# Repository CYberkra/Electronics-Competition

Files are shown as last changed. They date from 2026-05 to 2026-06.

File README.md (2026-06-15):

# AWG K325T — 任意波形信号发生器

> 第二十一届研电赛 · 优利德赛题二 FPGA 数字基带
> 目标器件：Xilinx Kintex-7 XC7K325TFFG900-2（正点原子 K7-325T）
> 子卡：FMCADDA-9250-9144 (AD9144 DAC)
> 扩展模块：KiCad PCB (ST7789 LCD + EC11 编码器 + Logo 丝印)

---

## 项目简介

基于 **K7-325T** + **AD9144 DAC** 的高速任意波形发生器，TX-only 纯信号生成设计。

### 核心指标

| 指标 | 值 | 赛题要求 |
|---|----|---|
| DAC | AD9144, 4ch 16bit, 2.8Gsps | ≥5GSa/s ⚠️ |
| 垂直分辨率 | 16 bit | ≥14bit ✅ |
| 频率分辨率 | 48bit DDS, ~μHz | ≤1mHz ✅ |
| JESD204B | TX 4L @10Gbps | — |
| 时钟 | LMK04828 (50M TCXO) | — |
| 控制 | UART 115200 + 按键 | — |

### 实测幅度 (2026-06-14, 满幅度 0x7FFF)

| 100kHz | 1MHz | 10MHz | 100MHz | 300MHz |
|---|---|---|---|---|
| 60mV | 120mV | 500mV | 680mV | 470mV |

### 频谱仪频域测试 (2026-06-16, 满幅度 0x7FFF)

| 指标 | 赛题要求 | 实测值 | 结果 |
|---|---|---|:--:|
| 谐波失真 (100MHz) | < -40 dBc | **-54.9 dBc** | ✅ |
| 带内平坦度 (10~300MHz) | < 3 dB | **2.6 dB** | ✅ |
| 线性扫频 (10~100MHz) | 支持 | 10 峰等间距 | ✅ |
| 对数扫频 (1~128MHz) | 支持 | 8 峰倍频程 | ✅ |

### 当前进度

- [x] JESD204B 4L @10Gbps 建链
- [x] LMK04828 SPI 时钟配置
- [x] SPI clock-enable 重构 (derived clock → clk_in + spi_tick)
- [x] DDS 4级流水线 (48bit, 4采样/周期, Sine LUT 4096×16bit)
- [x] 4种波形 (正弦/方波/三角/锯齿) + BRAM 任意波形
- [x] 扫频引擎 (线性 + 对数, sweep_engine.v)
- [x] SFCW/对数扫频寄存器 (0x50-0x6C) + FMCW chirp 模式
- [x] 幅度/偏置 Q1.15 缩放
- [x] 数字校准表实例化 (ad9144_awg_cal, BRAM 16bin 频率补偿)
- [x] UART 远程控制 (115200 8N1 ASCII 协议)
- [x] 板载按键控制 (KEY0/KEY1)
- [x] KiCad 扩展模块 (ST7789 + EC11, 含 Logo 丝印)
- [x] 竞赛文档 (设计文档 + 测试方案 + PPT)
- [x] EC11 FPGA 驱动 (正交解码 + 消抖 + AWG 桥接)
- [x] ST7789 FPGA 驱动 (SPI 驱动 + 字符渲染 + 菜单系统)
- [x] 频谱仪频域测试 (谐波失真 -54.9dBc, 平坦度 2.6dB)
- [ ] 外部放大器 (→3Vpp)
- [ ] TFT/EC11 上板验证 (PCB 物理问题待排查)

---

## 环境要求

| 项目 | 版本/路径 |
|---|---|
| **Vivado** | **2024.1** (2024.2+ 无 7 系 JESD IP) |
| 目标器件 | `xc7k325tffg900-2` |
| License | Synthesis + JESD204 |

---

## 快速开始

### 构建 & 烧录

```powershell
# 综合 → 实现 → Bitstream
& D:\Xilinx\Vivado\2024.1\bin\vivado.bat -mode batch -source scripts/build_all.tcl

# 烧录
& D:\Xilinx\Vivado\2024.1\bin\vivado.bat -mode batch -source scripts/program.tcl
```

### UART 控制

```python
python tools/set_freq.py 50000000  # 50MHz
# 或手动: W 08 00000003 (开控制) → W 10/14 (设频率) → W 2C 00000001 (应用)
```

---

## 仓库结构

```
Electronics-Competition/
├── rtl/               # Verilog RTL (top/ control/ dds/ dsp/ jesd/ sweep/ wave/)
├── constraints/       # XDC 约束 (awg_k325t.xdc, fmc_adda.xdc)
├── vivado/            # Vivado 工程
├── docs/tasks/        # 开发任务文档 (SFCW, GUI)
├── scripts/           # Tcl 构建/烧录脚本
├── tools/             # Python UART 工具
├── docs/competition/  # 竞赛文档 (设计文档/测试方案/PPT/视频脚本)
├── sim/               # 仿真 testbench
└── kicad/             # KiCad 扩展模块 PCB
```

## 扩展模块管脚

| 功能 | FPGA 引脚 | 备注 |
|---|---|---|
| TFT SPI (6pin) | N27/M24/M27/M25/N29/M20 | ST7789, P2 CMOS接口 |
| EC11 编码器 | L20/J21/J22 | CMOS_D1/D2/D3 |
| LEDK | L30 | CMOS_D4 |

约束已备注释在 `constraints/awg_k325t.xdc` §14，顶层端口待加。

---

## 关键文档

| 需求 | 位置 |
|---|---|
| 赛题原文 (官方PDF) | `docs/references/研电赛第21届技术竞赛赛题清单.pdf` |
| 赛题原文 (文本) | `docs/competition/uni-trend-problem-statement.md` |
| 设计文档 | `docs/competition/design_document.md` |
| 测试方案 | `docs/competition/AWG指标测试方案.md` |
| 测试记录 | `docs/competition/AWG指标测试结果记录.md` |
| 答辩 PPT | `docs/competition/竞赛答辩PPT.pptx` |
| PPT 大纲 | `docs/competition/答辩PPT内容大纲.md` |
| 视频脚本 | `docs/competition/video_script.md` |
| 技术论文 | `docs/competition/技术论文.md` |
| 交付物清单 | `docs/competition/交付物清单.md` |
| 扩展模块管脚 | `kicad/模块管脚分配表.csv` |
| SFCW/FMCW 任务 | `docs/tasks/SFCW_FMCW_波形生成任务.md` |
| TFT+EC11 GUI 任务 | `docs/tasks/TFT_Encoder_GUI_菜单系统任务.md` |

---

> **最后更新**: 2026-06-15

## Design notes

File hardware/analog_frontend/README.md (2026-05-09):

# AWG模拟前端设计说明

## 项目概述

本设计为K325T + AD9144 AWG项目的模拟前端模块，用于将AD9144 DAC输出信号进行增益控制、量程切换和50Ω匹配输出。

## 技术指标

| 参数 | 目标值 | 说明 |
|---|---|---|
| 输入 | AD9144子卡SMA输出 | 差分或单端，约2.7Vpp |
| 输出幅度范围 | 10mVpp ~ 3Vpp | 满足赛题要求 |
| 输出阻抗 | 50Ω | SMA接口 |
| 带宽 | ≥1GHz | -3dB |
| 控制接口 | SPI + GPIO | FPGA控制 |

## 电路拓扑

```
SMA输入(J1) → 巴伦(T1) → 固定增益放大(U1) → 数控衰减(U2) → 量程切换(K1) → 输出驱动(U3) → SMA输出(J2)
```

## 关键器件

### T1: TC1-1-13M+ (巴伦)
- 功能：差分转单端（如果子卡输出是差分）
- 带宽：4.5MHz ~ 3GHz
- 阻抗比：1:1

### U1: THS3491 (固定增益放大)
- 功能：将AD9144输出提升到足够电平
- 带宽：900MHz
- 增益：+6dB（约2倍）
- 供电：±5.5V

### U2: PE4302 (数控衰减器)
- 功能：精确控制输出幅度
- 衰减范围：0 ~ -31.5dB
- 步进：0.5dB
- 控制：并行数字接口（D0-D5 + LE + CLK）
- 带宽：1MHz ~ 4GHz

### K1: G6K-2F (量程切换继电器)
- 功能：切换高/低/超低量程
- 触点：DPDT
- 带宽：2GHz
- 线圈：5V

### U3: THS3491 (输出驱动)
- 功能：50Ω输出驱动
- 带宽：900MHz
- 增益：单位增益（或根据需要调整）

## 量程设计

| 量程 | 继电器状态 | 衰减网络 | 输出范围 |
|---|---|---|---|
| 高量程 | K1A闭合 | 0dB | 0.1V ~ 3Vpp |
| 低量程 | K1B闭合 | -20dB | 10mV ~ 300mVpp |
| 超低量程 | K1C闭合 | -40dB | 1mV ~ 30mVpp |

## 电源需求

- +5V @ 200mA（运放供电）
- -5V @ 100mA（运放负电源）
- +3.3V @ 50mA（PE4302逻辑、继电器驱动）

## FPGA控制接口

```
FPGA GPIO:
  - RANGE_SEL[1:0]: 量程选择（00=高, 01=低, 10=超低）
  - ATT_LE: PE4302锁存使能
  - ATT_CLK: PE4302时钟
  - ATT_D[5:0]: PE4302衰减数据
  - OUTPUT_EN: 输出使能
```

## 设计要点

1. **阻抗控制**：所有RF走线必须保持50Ω特性阻抗
2. **地平面**：完整的射频地平面，避免割裂
3. **去耦**：每个电源引脚0.1μF + 10μF陶瓷电容
4. **布局**：信号路径短直，继电器靠近输出端
5. **屏蔽**：高频部分加金属屏蔽罩

## 文件清单

- `awg_analog_frontend.kicad_pro` - KiCad项目文件
- `awg_analog_frontend.kicad_sch` - 原理图
- `awg_analog_frontend.kicad_pcb` - PCB布局
- `awg_analog_frontend.kicad_sym` - 符号库
- `awg_analog_frontend.bom.csv` - BOM清单

## 设计进度

### 已完成
- [x] **电源输入连接器(J3)**：3-pin端子，+5V/GND/-5V（已放置并连线到电源标签）
- [x] **FPGA控制接口连接器(J4)**：10-pin排针（已放置，引脚定义待标注）
- [x] 基础电源标签：+5V、-5V、GND

### 进行中
- [ ] 信号链器件放置（尚未开始）
- [ ] 原理图连线（尚未开始）

### 待完成
- [ ] 放置信号链核心器件：巴伦(T1)、THS3491(U1)、PE4302(U2)、继电器(K1)、输出驱动(U3)
- [ ] 放置SMA连接器(J1/J2)
- [ ] 完成电源电路连线（J3 → 各器件电源引脚）
- [ ] 添加AMS1117-3.3稳压器
- [ ] 添加去耦电容
- [ ] 完成控制接口标签（J4各pin定义并连接到PE4302/继电器）
- [ ] 添加继电器驱动电路
- [ ] 完成全局网络标签
- [ ] ERC电气规则检查
- [ ] PCB布局
- [ ] 阻抗仿真验证
- [ ] 打样与测试

## 参考文档

- AD9144 Datasheet
- THS3491 Datasheet (TI)
- PE4302 Datasheet (pSemi)
- G6K-2F Datasheet (Omron)
- TC1-1-13M+ Datasheet (Mini-Circuits)

---
设计日期：2026-05-08
设计者：[师妹姓名]
审核者：[导师/队长]

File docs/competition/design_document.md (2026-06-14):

# 任意波形信号发生器 — 方案设计与实现文档

## 1. 系统概述

### 项目背景与赛题理解

本项目面向第二十一届中国研究生电子设计竞赛"优利德"企业命题赛道赛题二——任意波形信号发生器设计。赛题要求基于 DDS 原理，通过嵌入式软硬件协同设计，构建一个高性能任意波形发生器。

赛题核心指标：采样率不低于 5 GSa/s、模拟带宽不低于 1 GHz、垂直分辨率不低于 14 bit、频率范围覆盖 1 mHz 至 1 GHz 且分辨率优于 1 mHz、谐波失真优于 -40 dBc、非谐波杂散优于 -60 dBc；同时要求 50 欧姆输出阻抗、幅度范围 10 mVpp 至 3 Vpp、幅度精度 1 mVpp、带内平坦度小于 3 dB，并具备线性/对数扫频功能。

本方案采用 Xilinx Kintex-7 系列 FPGA 作为数字基带平台，搭配 AD9144 高速 DAC 子卡实现 JESD204B 高速数据接口，通过全数字 DDS 引擎生成任意波形，支持板载按键和 UART 双重控制方式。

### 系统整体架构框图

```
┌──────────────────────────────────────────────────────────────────────┐
│                           正点原子 K7-325T 开发板                       │
│                                                                      │
│  ┌─────────┐  ┌──────────┐  ┌─────────────────────────────────┐     │
│  │ KEY0/1  │  │  UART    │  │        初始化状态机              │     │
│  │ 按键控制 │  │ 115200   │  │  LMK→JESD_RST→AXI→DAC→DONE     │     │
│  └────┬────┘  └────┬─────┘  └─────────────────────────────────┘     │
│       │             │                                                │
│       ▼             ▼                                                │
│  ┌──────────────────────────────────────────────────────────┐       │
│  │                 寄存器控制层 (awg_reg_bank)                │       │
│  │   频率字 │ 幅度Q15 │ 偏置 │ 波形选择 │ 校准使能 │ 输出使能  │       │
│  └──────────────────────────┬───────────────────────────────┘       │
│                             │                                        │
│                             ▼                                        │
│  ┌──────────────────────────────────────────────────────────┐       │
│  │              数字校准 (awg_cal) — BRAM 频率-增益补偿表     │       │
│  └──────────────────────────┬───────────────────────────────┘       │
│                             │                                        │
│                             ▼                                        │
│  ┌──────────────────────────────────────────────────────────┐       │
│  │           4路并行 DDS 引擎 (ad9144_awg_dds4)              │       │
│  │  ┌──────────┐ ┌──────┐ ┌──────────┐ ┌──────────┐        │       │
│  │  │ Sine LUT │ │Square│ │ Triangle │ │ Sawtooth │        │       │
│  │  │ 4096x16  │ │      │ │          │ │          │        │       │
│  │  └──────────┘ └──────┘ └──────────┘ └──────────┘        │       │
│  │  48bit 相位累加器 × 4 采样/拍 @ 250MHz                    │       │
│  │  DSP48 乘法器 (幅度缩放 Q15) + 偏置叠加 + 饱和限幅         │       │
│  └──────────────────────────┬───────────────────────────────┘       │
│                             │                                        │
│                             ▼                                        │
│  ┌──────────────────────────────────────────────────────────┐       │
│  │              Sample Packer (4×16bit → 128bit JESD 字)     │       │
│  └──────────────────────────┬───────────────────────────────┘       │
│                             │                                        │
│             ┌───────────────┼───────────────┐                       │
│             ▼               ▼               ▼                       │
│  ┌──────────────────┐ ┌──────────────┐ ┌──────────────────┐        │
│  │ JESD204B TX Core │ │   GTXE2 PHY  │ │  clk_for_glblclk │        │
│  │   4L @10Gbps     │ │ QPLL + 4 GTX │ │  MMCM (125→250M) │        │
│  │   Subclass 1     │ │              │ │                  │        │
│  └────────┬─────────┘ └──────┬───────┘ └──────────────────┘        │
│           │                  │                                       │
├───────────┴──────────────────┴──────────────────────────────────────┤
│                         FMC HPC 连接器                               │
├───────────┬──────────────────┬──────────────────────────────────────┤
│           │                  │                                       │
│  ┌────────▼──────────┐  ┌───▼──────────────┐                       │
│  │  AD9144 DAC       │  │  LMK04828 PLL    │                       │
│  │  4ch 16bit 2.8G   │  │  50M TCXO→125M/  │                       │
│  │  JESD204B 4L      │  │  250M + SYSREF   │                       │
│  └───────────────────┘  └──────────────────┘                       │
│                                                                      │
│  ┌──────────────────────────────────────────────────────────┐       │
│  │         扩展模块 (KiCad PCB, 含研电赛Logo丝印)              │       │
│  │   ST7789 显示屏 + EC11 旋转编码器 (辅助交互)                 │       │
│  │   本地交互: 波形选择/频率调节/幅度控制/扫频参数设置           │       │
│  └──────────────────────────────────────────────────────────┘       │
└──────────────────────────────────────────────────────────────────────┘
```

### 主要技术指标对标

| 序号 | 指标项 | 赛题要求 | 本方案实现 | 备注 |
|:----:|---|---|---|---|
| 1 | 采样率 | ≥ 5 GSa/s | 2.8 GSa/s (AD9144上限) | 见 5.3 节差距分析 |
| 2 | 模拟带宽 | ≥ 1 GHz | [预计: ~800 MHz @ 2.8G] | 实测待补 |
| 3 | 垂直分辨率 | ≥ 14 bit | 16 bit (DAC 物理位宽) | 数字基带 Q15 格式 |
| 4 | 正弦最小频率 | ≤ 1 mHz | 48 bit 累加器，理论 ~8.88e-7 Hz | 满足，远超指标 |
| 5 | 最高输出频率 | ≥ 1 GHz | [预计: ~1 GHz @ 内插+镜像] | AD9144 支持 4x 内插 |
| 6 | 频率分辨率 | ≤ 1 mHz | 250 MHz / 2^48 ≈ 8.88e-7 Hz | 满足，远超指标 |
| 7 | 谐波失真 | < -40 dBc | [待测试] | 受限于 DAC SFDR |
| 8 | 非谐波杂散 | < -60 dBc | [待测试] | 需外部低通滤波 |
| 9 | 输出阻抗 | 50 Ω | [待确认 — 子卡变压器耦合] | 子卡默认 50 Ω |
| 10 | 幅度范围 | 10 mVpp ~ 3 Vpp | [待测试] | Q15 缩放 + 校准 |
| 11 | 幅度精度 | ≤ 1 mVpp | [待测试] | 依赖校准表标定 |
| 12 | 带内平坦度 | < 3 dB | [待测试] | 数字校准补偿 |
| 13 | 扫频功能 | 线性/对数 | 线性扫频已实现 | 对数扫频可扩展 |
| 14 | 通道数 | ≥ 1 | 4 通道 | AD9144 提供 4ch |

---

## 2. 硬件平台设计

### 2.1 主控 FPGA 选型

**型号**：XC7K325TFFG900-2 (Kintex-7)，搭载于正点原子 K7-325T 开发板。

**选型理由**：

| 选型因子 | 分析 |
|---|---|
| GTX 高速收发器 | K325T 提供 16 个 GTX transceiver，最大线速率 12.5 Gbps。本设计使用 4 个 TX 通道运行在 10 Gbps (lane rate)，可满足 JESD204B protocol overhead 后的有效带宽需求。剩余 12 个通道可用于后续扩展。 |
| 逻辑资源 | 326,080 个 Logic Cells，840 个 DSP48E1 Slice，445 个 36Kb BRAM。本设计的数字基带逻辑（DDS、校准、UART、SPI 控制器）占用资源极少（< 15%），有充分余量用于后续 DDR3 波形存储和信号处理扩展。 |
| FMC HPC 接口 | 板载 FMC HPC (High Pin Count) 连接器直接对接到 Bank 117 的 GTX Bank，物理上与 FMCADDA-9250-9144 子卡兼容，无需额外转接板。 |
| 开发周期 | 正点原子开发板提供成熟的原理图、板级支持和示例工程，可缩短竞赛准备周期。 |
| 速度等级 | -2 速率等级支持 GTX 10 Gbps 运行，满足 JESD204B 4L @ 10Gbps 的时序要求。温度等级 I 满足实验室环境要求。 |

**资源利用率预估**：

| 资源 | 预估用量 | K325T 总量 | 利用率 |
|---|---|---|---|
| LUT | ~15,000 | 203,800 | ~7% |
| FF | ~18,000 | 407,600 | ~4% |
| BRAM (36Kb) | ~50 | 445 | ~11% |
| DSP48E1 | ~20 | 840 | ~2% |
| GTX Channel | 4 TX | 16 | 25% |
| MMCM/PLL | 3 | 10 | 30% |

### 2.2 DAC 子卡

**型号**：FMCADDA-9250-9144 (Analog Devices 官方 FMC 子卡)

**AD9144 关键参数**：

| 参数 | 规格 | 说明 |
|---|---|---|
| 分辨率 | 16 bit | 满足 14 bit 垂直分辨率要求 |
| 最大采样率 | 2.8 GSa/s (DAC clock 1.4 GHz, DDR 模式) | 低于赛题 5G 指标，见 5.3 节分析 |
| 通道数 | 4 | 可独立输出四路波形 |
| 数据接口 | JESD204B Subclass 1 | 4 lanes @ 10 Gbps |
| 内插 | 1x / 2x / 4x / 8x | 使用 4x 内插降低 FPGA 侧数据率 |
| 模拟输出 | 差分电流输出，变压器耦合转单端 50 Ω | 满量程 20 mA |
| SFDR | ~70 dBc @ 100 MHz 输出 (datasheet 典型) | 窄带 SFDR 性能良好 |

**模拟前端考虑**：

- DAC 输出经板载变压器转换为单端 50 Ω，可直接驱动 50 Ω 负载。
- 在数字域实现幅度缩放（Q15 格式乘法），16bit 精度满足 1mVpp 幅度步进要求。
- 通过数字校准表补偿 DAC 输出级的非平坦特性。
- AD9144 的 16bit 物理位宽和 4 通道能力是其核心优势，在垂直分辨率上超过赛题 14bit 要求。

### 2.3 时钟系统

**LMK04828 PLL 架构**：

子卡搭载 LMK04828 双 PLL 时钟净化器，以板载 50 MHz TCXO 为参考源，通过内部 PLL1 + PLL2 级联产生系统所需全部时钟。

**时钟树**：

```
50 MHz TCXO (板载, LMK04828 OSCin)
    │
    ▼
LMK04828 ──┬── PLL1 (鉴相/环路滤波) → PLL2 (VCO ~2925 MHz)
           │       │
           │       ├── OUT4:  125 MHz → FMC GBTCLK0 (G8/G7) → GTX QPLL RefClk
           │       ├── OUT6:  125 MHz → FMC glblclk (D17/D18)
           │       │           │
           │       │           └── clk_for_glblclk MMCM
           │       │               ├── rx_core_clk: 125 MHz (RX 逻辑, 当前未用)
           │       │               └── tx_core_clk: 250 MHz (DDS + JESD TX)
           │       └── OUT9:  SYSREF → FMC LA20 (D14/C14) → JESD204B SYSREF
           │
           └── CLKout 输出分频器可编程配置
```

**板载 100 MHz 差分时钟** (K325T 开发板自带)：

```
100 MHz 差分 (AE10/AF10)
    → IBUFDS → BUFG → sys_clk_bufg (100 MHz)
        │
        ▼
    STARTUPE2 → CFGMCLK (65 MHz)
        │
        ▼
    clk_sys_mmcm
        ├── clk_25m     (SPI 控制时钟, 25 MHz)
        └── clk_axi_100m (AXI-Lite 配置时钟, 100 MHz)
```

**JESD204B SYSREF**：

SYSREF 信号是实现 JESD204B Subclass 1 确定性延迟的关键。LMK04828 产生的 SYSREF 脉冲同时分发至 FPGA (通过 FMC LA20 管脚) 和 AD9144，确保发送端和接收端在相同的 LMFC (Local Multi-Frame Clock) 边界上对齐。SYSREF 的频率通过 LMK04828 寄存器编程为 LMFC 周期整数分频。

### 2.4 电源与接口

**FMC HPC 连接器**：

- 物理标准：VITA 57.1 FMC HPC (High Pin Count)，400-pin。
- 连接 Bank：FPGA Bank 117 (GTX bank, MGT 供电 1.05V/1.2V)。
- 高速信号：4 对 C2M (FPGA→子卡, DAC TX)。
- 控制信号：SPI (3 线) × 2 套 (LMK04828, AD9144)，复位，SYNC，SYSREF，子卡在位检测。

**关键电源轨 (子卡侧)**：

| 电源轨 | 电压 | 用途 |
|---|---|---|
| VADJ | 2.5V | FMC IO Bank 供电, SPI 和同步信号 |
| 3P3V | 3.3V | 子卡辅助电源, LMK04828 |
| 1P8V | 1.8V | AD9144 DVDD18, LMK04828 |
| 1P2V | 1.2V | AD9144 DVDD12 |
| 3P3VA / 1P8VA / -1P2V | 模拟供电 | DAC 模拟域 |

### 2.5 PCB 丝印合规说明

赛题要求"绘制电路板时丝印层需要打印研电赛 Logo 及日期"。但本项目的核心硬件——正点原子 K7-325T 开发板和 FMCADDA-9250-9144 子卡——均为成品采购，无法修改丝印。

为此，本项目设计了一块简单的 KiCad 扩展 PCB，搭载 ST7789 1.69" 显示屏和 EC11 旋转编码器，在 PCB 丝印层印制研电赛 Logo 及日期，满足赛题合规要求。该扩展板通过排针连接到 FPGA 开发板 GPIO，同时提供了本地参数显示和旋钮调节的辅助交互功能。

| 器件 | 规格 | 说明 |
|---|---|---|
| 显示屏 | ST7789 1.69" TFT, 240×280 | SPI 接口，参数/状态显示 |
| 旋转编码器 | EC11, 20脉冲/圈, 带按键 | 频率/幅度/波形本地调节 |
| 丝印 | 研电赛 Logo + 日期 | 满足赛题 PCB 丝印硬性要求 |

---

## 3. FPGA 数字基带设计

### 3.1 顶层架构

**模块层次** (对应 `rtl/top/awg_top.v`)：

```
awg_top
├── 时钟系统
│   ├── IBUFDS (100M sys_clk) + BUFG
│   ├── STARTUPE2 → CFGMCLK (65M)
│   ├── clk_sys_mmcm  → clk_25m, clk_axi_100m
│   ├── IBUFDS_GTE2 (125M refclk)
│   └── clk_for_glblclk MMCM → tx_core_clk (250M), rx_core_clk (125M)
├── rst_module (异步复位同步释放, 25M 域)
├── 初始化状态机 (7 态 FSM)
├── SPI 配置层
│   ├── lmk_spi_wr_config (LMK04828)
│   └── ad9144_spi_wr_config (AD9144)
├── 控制层
│   ├── awg_key_ui_ctrl (按键 UI)
│   ├── ad9144_uart_reg_bridge (UART 桥, AWG_UART_CONTROL 宏控制)
│   └── ad9144_awg_reg_bank (寄存器组)
├── 信号处理链
│   ├── ad9144_awg_cal (数字校准)
│   ├── ad9144_awg_dds4 (4路并行 DDS)
│   └── ad9144_sample_packer (128bit 拼接)
├── JESD204B 链路
│   ├── jesd204_phy_0 (GTXE2 PHY)
│   └── jesd204_tx (TX Core IP)
└── 调试/指示
    ├── awg_led_status (LED 驱动)
    ├── ila_awg_debug (ILA 集成逻辑分析, AWG_DEBUG_ILA 宏控制)
    └── vio_for_jesd_rst (VIO 虚拟 IO)
```

**时钟域划分**：

| 时钟域 | 频率 | 来源 | 用途 |
|---|---|---|---|
| sys_clk | 100 MHz | 板载 100M 差分 | 系统基准，LED，按键采样 |
| cfg_clk | 65 MHz | STARTUPE2 CFGMCLK | MMCM 源 |
| clk_25m | 25 MHz | clk_sys_mmcm | SPI 控制，初始化状态机 |
| clk_axi_100m | 100 MHz | clk_sys_mmcm | JESD TX AXI-Lite 配置 |
| tx_core_clk | 250 MHz | clk_for_glblclk | DDS，JESD TX Core |
| rx_core_clk | 125 MHz | clk_for_glblclk | (保留，后续扩展预留) |
| qpll_refclk | 125 MHz | IBUFDS_GTE2 | GTX QPLL 参考时钟 |

**源文件引用**：
- `rtl/top/awg_top.v` — 顶层模块，含完整端口定义和模块例化
- `rtl/jesd/rst_module.v` — 异步复位同步释放模块

**复位策略**：

- 系统上电后，MMCM 锁定之前，系统处于复位状态（`rst_module` 产生 `w_rst_n`）。
- `rst_module` 采用异步复位同步释放策略，在 clk_25m 时钟域产生干净的复位信号。复位使能条件为 `EOS_n & clk_mmcm_locked`，确保 CFGMCLK 和 MMCM 都就绪后才释放。
- JESD204B TX Core 复位通过初始化状态机控制 (`r_jesd_tx_sys_reset` + VIO 调试开关)，确保在 LMK04828 配置完成后、时钟稳定后才释放。

**初始化状态机** (7 态 FSM @ clk_25m)：

| 状态 | 操作 | 过渡条件 |
|---|---|---|
| S0 (IDLE) | 清除 valid | 无条件 → S1 |
| S1 | 等待 lmk_datain_ready，使能 LMK SPI 写入 | ready → S2 |
| S2 | LMK SPI 写握手完成 | 无条件 → S3 |
| S3 | 等待 LMK SPI 空闲 (ready 下降沿) | ready=0 → S4 |
| S4 | JESD TX 复位与 AXI 配置阶段。分三子阶段：(a) 保持复位 1000 拍 @25MHz (40us)；(b) 释放复位 20000 拍 (800us) 等 PLL 锁定；(c) 关闭 AXI ena 40000 拍 (1.6ms) 等 AXI 写入完成 | 子阶段完成 → S5 |
| S5 | 等待 das_datain_ready，使能 AD9144 SPI 写入 | ready → S6 |
| S6 | 等待 AD9144 SPI 完成 | ready=0 → S7 |
| S7 | 运行态 (DONE) | 驻留 |

**LED 指示**：init state 显示在 LED 上。QPLL 锁定后 LED 全亮 (2'b11)；锁定前 LED 显示当前状态机编号的低 2 位，用于板级故障定位。

### 3.2 DDS 波形生成

**源文件**：`rtl/jesd/ad9144_awg_dds4.v`

**架构特点**：为匹配 JESD204B TX Core 的数据接口速率，DDS 引擎在每个 tx_core_clk (250 MHz) 周期同时产生 4 个采样点，合 1 GSa/s 的数据率。经 AD9144 内部 4x 内插后等效 DAC 采样率达到 4 GSa/s（实际受限于 AD9144 的 DAC clock 上限 1.4 GHz，即 2.8 GSa/s 的 DDR 输出）。

**48 bit 相位累加器**：

```
每个 tx_core_clk 周期（250 MHz）:
  phase_acc  ←  phase_acc + (phase_inc << 2)    // 4 采样/周期

四个并行的相位值:
  phase0 = phase_base = phase_acc + phase_offset
  phase1 = phase0   + phase_inc
  phase2 = phase0   + (phase_inc << 1)          // 2× phase_inc
  phase3 = phase0   + (phase_inc << 1) + phase_inc  // 3× phase_inc

频率分辨率:
  Δf = f_clk / 2^48 = 250e6 / 2^48 ≈ 8.88e-7 Hz  (< 1 mHz 要求)
```

**Sine LUT**：4 个独立的 Block ROM (`(* rom_style = "block" *)`)，每个深度 4096 条目 × 16 bit 宽度。使用相位累加器的高 12 位寻址 (`phase[N][47:36]`)，等价于将 0~2π 映射到 0~4095 的 12 bit 量化相位。正弦表数据通过 `$readmemh` 从外部 HEX 文件初始化，从 `phase_addr0`/`phase_addr1` 端口可观测当前正弦查表地址用于校准模块。

**非正弦波形生成** (通过 `shape_from_addr` function 组合逻辑计算，零 ROM 开销)：

| 波形 (wave_mode) | 生成算法 | 说明 |
|---|---|---|
| 0: Sine | LUT 查表 | 4096 条目 × 16bit 正弦 |
| 1: Triangle | 相位折返：上升段 `half_addr`, 下降段 `2047-half_addr`，中心化至 [-32768,32767] | 无 DSP 开销 |
| 2: Square | 相位最高位判决：MSB=0 → +32767, MSB=1 → -32768 | 零延迟 |
| 3: Sawtooth | 线性相位映射到 [-32768, 32767] | 无 LUT 开销 |

**关键设计细节**：

- 三角波和方波的 wave_mode 编码与寄存器组一致：三角波=1, 方波=2（代码注释中有 "FIX: swapped 2'd1(triangle) and 2'd2(square) to match register bank encoding"）。
- 波形类型 0 (sine) 走 `select_raw_sample` 选择正弦 LUT 输出，类型 1/2/3 走组合逻辑。

**流水线结构** (3 级流水)：

```
Stage 0: phase_acc 更新 → addr0~3 计算 (从 phase[47:36] 取高 12 位)
Stage 1: ROM 读 (sine_rom) + 波形 shape 计算 (shape_from_addr) → select_raw_sample mux
Stage 2: DSP48 乘法 (raw_sample × amplitude_q15) → 右移 15 位恢复 → 叠加 offset → 饱和限幅
Stage 3: 输出寄存 (sample0~3, phase_addr0~1, sample_valid)
```

`sample_valid` 在流水线填充 3 拍后持续有效。

### 3.3 幅度与偏置控制

**定点数格式**：
- 原始采样值 (raw)：`signed [15:0]`，范围 [-32768, 32767]
- 幅度控制字：`[15:0]`，Q1.15 无符号定点格式，`0x8000 = 1.0` (单位增益)，`0x4000 = 0.5` (半幅)
- 偏置控制字：`signed [15:0]`，与采样值相同标度

**DSP48 缩放链** (在 `ad9144_awg_dds4` 的 Stage 2, `scale_and_saturate` function)：

```
product = signed(raw_sample) * unsigned(amplitude_q15)   // 16×16 → 33 bit signed
shifted = product >>> 15                                  // 恢复 16 bit 范围
summed  = shifted + offset                                // 叠加偏置
saturated = clamp(summed, -32768, 32767)                  // 饱和限幅
```

**数字校准表** (`rtl/jesd/ad9144_awg_cal.v`)：

- 16 条目标定条目 (BRAM)，每条 32 bit：`{offset[15:0], gain_coef[15:0]}`
- 频率索引：取 `phase_inc[47:44]` 高 4 位，将频率范围划分为 16 个 bin
- 补偿公式：`amplitude_out = (amplitude_in × gain_coef) >> 15 + offset`
- 补偿在 cal_enable=1 时插入 DDS 幅度通道前，旁路时直通
- 默认值：所有条目初始化为单位增益 (0x8000)、零偏置 (0x0000)
- 校准表可通过 UART 在线写入 (地址 0x40~0x7C) 和读取

**信号处理链路 (awg_core.v)**：

源文件 `rtl/dsp/awg_core.v` 提供可复用前端：DDS NCO → sine LUT + wave_shape_gen → bram_wave_player → sample_mux (4 选 1) → amp_offset_scale。在顶层 `awg_top.v` 中，实际使用的信号链为 `ad9144_awg_dds4` 模块（集成度更高的版本），其内部已包含完整的 DDS + LUT + 幅度偏置处理流水线。

### 3.4 扫频引擎

**源文件**：`rtl/sweep/sweep_engine.v`

**工作模式**：

| 参数 | 配置 | 说明 |
|---|---|---|
| DWELL_TICKS | 可配置 | 每个频率点驻留时间，单位时钟周期 |
| START_INC | 可配置 | 起始频率对应的 phase_inc |
| STOP_INC | 可配置 | 终止频率对应的 phase_inc |
| STEP_INC | 可配置 | 频率步进对应的 phase_inc 增量 |

**扫频算法** (线性双向扫频)：

```
enable=1 时:
  phase_inc_out = sweep_inc
  每个 DWELL_TICKS 周期:
    正向(sweep_dir=0): sweep_inc += STEP_INC, 到达 STOP_INC 后反向
    反向(sweep_dir=1): sweep_inc -= STEP_INC, 到达 START_INC 后反向

enable=0 时:
  phase_inc_out = manual_phase_inc (直通旁路)
```

**示例默认参数** (100 MHz 系统时钟时)：
- START_INC = `0x004189374BC7` (100 kHz)
- STOP_INC = `0x028F5C28F5C3` (1 MHz)
- STEP_INC = `0x004189374BC7` (100 kHz 步进)
- DWELL_TICKS = 5,000,000 (50 ms @ 100 MHz)

当前实现为线性扫频 (双向上下扫)。对数扫频可通过修改步进逻辑为乘性因子实现。

在 `awg_core.v` 中，扫频引擎在 wave_mode=6 (扫频模式) 时激活，直接驱动 DDS NCO 的 phase_inc。

### 3.5 BRAM 任意波形回放

**源文件**：`rtl/wave/bram_wave_player.v`

- 4096 条目 × 16 bit 的推断 ROM，通过外部相位地址索引
- 默认初始化为梯形/三角波（通过 `make_sample` function 在 initial 块中生成）
- 波形数据分 4 段：上升沿 (0x8000→0x7FFF)，高平顶 (0x7FFF)，下降沿 (0x7FFF→0x8000)，低平底 (0x8000)
- 在 `awg_core` 的 `sample_mux` 中，通过 wave_mode 选择 BRAM 输出
- 后续扩展方向：通过 UART 下载自定义波形数据到 ROM 地址空间

### 3.6 JESD204B 高速接口

**TX 配置** (AD9144 Mode 4)：

| 参数 | 设置 | 说明 |
|---|---|---|
| Lanes (L) | 4 | 4 条高速链路 |
| Converters (M) | 4 | 4 个 DAC 转换器 |
| Samples/Converter/Cycle (S) | 1 | 每转换器每帧周期 1 采样 |
| Octets/Frame (F) | 4 | 每帧 4 octets (16 bit × 4 通道 / 8) |
| Frames/Multiframe (K) | 32 | 每多帧 32 帧 |
| Lane Rate | 10 Gbps | = M × S × N' × (10/8) × f_sample / L |
| Line Coding | 8B/10B | JESD204B 标准编码 |
| Subclass | 1 | 使用 SYSREF 实现确定性延迟 |
| Scrambling | Enabled | 降低 EMI 和频谱峰值 |

**数据映射**：

```
128 bit JESD TX Data Word (w_tx_tdata → tx_tdata):
  [31:0]   = sample0 (Channel 0)
  [63:32]  = sample1 (Channel 1)
  [95:64]  = sample2 (Channel 2)
  [127:96] = sample3 (Channel 3)

ad9144_sample_packer 模块将 4 个 16 bit 采样拼接:
  {sample3[15:0], sample2[15:0], sample1[15:0], sample0[15:0]} → 128 bit
```

**源文件**：
- `rtl/jesd/ad9144_sample_packer.v` — 4×16bit → 128bit 拼接
- `rtl/jesd/jesd_axi_write.v` — AXI-Lite 配置写入模块

**SYNC~ 握手流程**：

1. FPGA 侧通过初始化状态机释放 JESD TX 复位
2. GTX QPLL 锁定 (`common0_qpll_lock_out` = 1)
3. FPGA 等待 AD9144 拉高 SYNC~ (表示 DAC 侧 CGS (Code Group Sync) 完成)
4. FPGA 在下一个 LMFC 边界发送 ILAS (Initial Lane Alignment Sequence)
5. AD9144 验证 ILAS 后进入 DATA 阶段 (正常数据传输)

**SYSREF 处理**：
- SYSREF 通过 IBUFDS 从 FMC LA20 (D14/C14) 进入 FPGA 内部
- JESD204 TX Core IP 内部在 SYSREF 上升沿对齐内部 LMFC 计数器
- Subclass 1 保证 FPGA 发送端与 AD9144 接收端的 LMFC 边界在确定时钟周期内对齐

---

## 4. 控制与通信

### 4.1 板载按键控制

**源文件**：`rtl/control/awg_key_ui_ctrl.v`

**按键布局与功能**：

| 按键 | 短按 | 长按 (>250ms) | 组合键 |
|---|---|---|---|
| KEY0 | 选中参数递增 | — | — |
| KEY1 | 切换当前参数页面 | — | KEY0+KEY1 同时按：频率装载 |

**参数页面 (UI 模式)**：

| ui_mode | 页面名称 | 可调节参数 |
|---|---|---|
| 0 | 频率选择 | 频率范围组 (粗调) |
| 1 | 波形选择 | Sine / Square / Triangle / Sawtooth |
| 2 | 幅度控制 | 幅度 Q15 值 |
| 3 | 偏置控制 | 偏置值 |

**去抖设计**：

```
DEBOUNCE_TICKS = 2,000,000   // 20ms @ 100 MHz (按键稳定时间)
CHORD_TICKS    = 25,000,000  // 250ms @ 100 MHz (组合键检测阈值)
```

按键状态通过 `awg_reg_bank` 的只读 BUTTON_STATE 寄存器 (地址 0x30) 可远程查询。

### 4.2 UART 远程控制

**源文件**：`rtl/jesd/ad9144_uart_reg_bridge.v`（UART 桥接），`rtl/jesd/uart_rx.v`（UART 接收），`rtl/jesd/uart_tx.v`（UART 发送）

**物理层参数**：

| 参数 | 值 |
|---|-----|
| 波特率 | 115200 |
| 数据位 | 8 |
| 停止位 | 1 |
| 校验位 | 无 (N) |
| 流控 | 无 |
| 电气接口 | 3.3V LVTTL (板载 CH340G USB-UART, FPGA 引脚 T23/T22) |
| 编译控制 | `AWG_UART_CONTROL` 宏 (不定义则 UART 桥接不例化) |

**命令协议** (ASCII 文本，换行分隔)：

```
写入: W <AA> <DDDDDDDD><CR><LF>
  W   - 写入命令前缀 (大小写不敏感)
  AA  - 2 位十六进制地址 (00~FF)
  DDDDDDDD - 8 位十六进制数据 (32 bit)
  示例: W 20 00008000  — 写入地址 0x20, 数据 0x00008000

读取: R <AA><CR><LF>
  R   - 读取命令前缀
  AA  - 2 位十六进制地址
  示例: R 0C  — 读取状态寄存器 (地址 0x0C)

读取流程: R命令→cfg_rd_en脉冲→2周期等待→捕获cfg_rdata→发送响应
```

**响应格式**：

```
OK<CR><LF>           — 写入成功
D <DDDDDDDD><CR><LF> — 读取返回数据 (前缀 D + 空格 + 8 位 hex)
ERR<CR><LF>          — 命令格式错误或非法字符
```

**UART 桥接状态机** (14 态 FSM @ 250 MHz)：
- IDLE → W_ADDR/W_DATA/W_EOL (写入流水线)
- IDLE → R_ADDR/R_EOL/RD_PULSE/RD_WAIT/RD_WAIT2/RD_CAPTURE (读取流水线)
- DRAIN_ERR (错误恢复：丢弃直到换行，回复 ERR)
- SEND/SEND_BUSY/SEND_IDLE (响应发送流水线)

**寄存器映射表** (对应 `rtl/jesd/ad9144_awg_reg_bank.v`)：

| 地址 | 寄存器名 | 位宽 | 访问 | 默认值 | 描述 |
|---|---|---|---|---|---|
| 0x00 | ID | 32 | R | 0x41574731 | 核心标识 ("AWG1") |
| 0x04 | VERSION | 32 | R | 0x20260507 | 固件版本号 |
| 0x08 | CONTROL | 32 | R/W | 0x00000001 | [1] use_reg_control, [0] output_enable |
| 0x0C | STATUS | 32 | R | — | tx_ready, tx_sync, sysref_seen, sample_valid, update_toggle, range_sel, cal_enable 等 |
| 0x10 | PHASE_INC_LO | 32 | R/W | — | 相位增量低 32 bit |
| 0x14 | PHASE_INC_HI | 32 | R/W | — | 相位增量高 16 bit (在[15:0]) |
| 0x18 | PHASE_OFFSET_LO | 32 | R/W | — | 相位偏置低 32 bit |
| 0x1C | PHASE_OFFSET_HI | 32 | R/W | — | 相位偏置高 16 bit |
| 0x20 | AMPLITUDE | 32 | R/W | 0x6000 | 幅度 Q15 [15:0] (0x6000 = 0.75 满幅) |
| 0x24 | OFFSET | 32 | R/W | 0x0000 | 直流偏置 signed[15:0] |
| 0x28 | WAVE_MODE | 32 | R/W | 0x0 | 波形 [1:0]: 0=Sine, 1=Triangle, 2=Square, 3=Saw |
| 0x2C | APPLY | 32 | W | — | 写任意值触发 update_toggle 翻转 (参数生效) |
| 0x30 | BUTTON_STATE | 32 | R | — | 按键状态只读镜像 |
| 0x34 | RANGE_SEL | 32 | R/W | 0x0 | 幅度范围选择 [1:0] |
| 0x38 | OUTPUT_EN | 32 | R/W | — | `CONTROL[0]`输出使能别名 |
| 0x3C | CAL_ENABLE | 32 | R/W | 0x0 | 数字校准使能 [0] |
| 0x40~0x7C | CAL_TABLE[0:15] | 32×16 | R/W | {0x0000,0x8000} | 校准系数表: [31:16]=signed offset, [15:0]=unsigned Q1.15 gain |
| 0x44 | DIAG | 32 | R | — | 调试: init_state[7:4], glblclk_mmcm_locked[1] |

**控制优先级**：

```
UART 控制 (use_reg_control=1) > 按键控制 (use_reg_control=0, 默认上电状态)
```

向 CONTROL 寄存器写入 `0x00000003` (bit0=1 output_enable + bit1=1 use_reg_control) 即可切换到 UART 远程控制模式。

**频率控制字计算**：

```
相位增量 phase_inc = f_out × 2^48 / f_clk
其中 f_clk = 250 MHz (tx_core_clk, 每拍 4 采样等效 1 GHz 数据率)

示例:
  10 MHz:  phase_inc = 10e6 × 2^48 / 250e6  ≈ 0x0A3D70A3D70A
  50 MHz:  phase_inc = 50e6 × 2^48 / 250e6  ≈ 0x333333333333
  100 MHz: phase_inc = 100e6 × 2^48 / 250e6 ≈ 0x666666666666
```

频率控制字默认值：`48'h0CCCCCCCCCCD` (~50 MHz @ 250 MHz 时钟)。

### 4.3 SPI 设备配置

**通用 SPI 控制器**：`rtl/jesd/spi_wr_rd_single.v` — 三线半双工 SPI (SCLK + SDIO + CS#)，运行在 25 MHz 时钟域 (clk_25m)。所有 3 个 SPI 目标设备实例化同一个基础模块，通过封装层差异化寄存器序列。

**LMK04828 配置** (通过 `rtl/jesd/lmk_spi_wr_config.v` 封装)：

- 配置 PLL1 R 分频器 (50M 参考 → 鉴相频率)
- 配置 PLL2 N 分频器 (VCO 锁定频率 ~2925 MHz)
- 配置时钟输出分频器：OUT4 (125 MHz, GBTCLK0), OUT6 (125 MHz, glblclk), OUT9 (SYSREF 脉冲)
- 配置 SYSREF 模式：脉冲模式，与 LMFC 对齐
- 使能 SYNC 分发至所有时钟输出

**AD9144 配置** (通过 `rtl/jesd/ad9144_spi_wr_config.v` 封装)：

- 配置 JESD204B 链路参数 (L=4, M=4, S=1, F=4, K=32)
- 配置内插倍数 (4x)
- 配置 DAC PLL（如果使用内部 PLL 模式）
- 使能 TX 通道和输出
- TXEN0/TXEN1 在顶层硬连线为 1'b1 (始终使能)

**SPI 配置说明**：
- 当前仅使用 LMK04828 和 AD9144 的 SPI 配置，两者共享 `spi_wr_rd_single` 控制器
- 写入基础寄存器以防止未配置状态造成电源/时钟异常

**SPI 配置握手**：各 SPI 封装模块提供 `datain_valid` / `datain_ready` 握手接口。初始化状态机通过这两个信号管理 LMK 和 DAC 的顺序配置流程。

---

## 5. 关键技术难点与解决方案

### 5.1 高速 JESD204B 链路建立

**难点**：10 Gbps × 4 Lane 的 JESD204B 链路稳定建立是系统最核心的挑战。涉及 QPLL 锁定、GTX 初始化、CGS (Code Group Sync)、ILAS (Initial Lane Alignment Sequence) 和 SYSREF 确定性延迟等多个环节的时序协调。

**解决方案**：

1. **初始化顺序严格编排**：通过顶层 7 态 FSM (clk_25m 域) 确保 LMK04828 时钟先稳定，再释放 JESD TX 复位，然后配置 AXI-Lite (JESD Core IP 寄存器)，最后配置 AD9144 SPI。这一顺序保证链路两侧的时钟和配置都就绪后才开始 SYNC~ 握手。

2. **GTX 初始化**：使用 QPLL (Quad PLL) 将 125 MHz 参考时钟倍频至 10 Gbps lane rate。QPLL 锁定 (`common0_qpll_lock_out`) 是链路建立的前置条件，LED 指示提供直观状态反馈 (QPLL lock → LED=2'b11)。

3. **SYNC~ 握手监控**：`dac_sync0` 通过 IBUFDS (E19/D19, LVDS_25) 进入 FPGA，连接至 JESD204 TX Core 的 `tx_sync` 端口。寄存器组 STATUS (0x0C) 提供 `tx_sync` 和 `sysref_seen` 状态只读，可通过 UART 查询链路健康状态。

4. **VIO 辅助调试**：`vio_for_jesd_rst` 提供 Vivado 硬件管理器内手动控制 JESD TX 复位的功能 (`w_jesd_tx_sys_reset_vio`)，与状态机复位 (`r_jesd_tx_sys_reset`) 或逻辑，方便在硬件调试时动态触发复位。

5. **眼图优化考虑**：
   - GTX TX 差分摆幅和预加重可通过 DRP (Dynamic Reconfiguration Port) 接口动态调整
   - PCB 走线长度匹配在 FMC HPC 标准内由子卡设计保证
   - [待测试] 通过示波器在子卡 SMA 连接器处测量接收端眼图，验证 10 Gbps 信号质量

### 5.2 多时钟域数据同步

**难点**：系统存在 6 个独立时钟域 (sys_clk @100M, cfg_clk @65M, clk_25m @25M, clk_axi_100m @100M, tx_core_clk @250M, rx_core_clk @125M, qpll_refclk @125M)，控制信号跨域频繁。

**CDC 策略** (对应约束文件 `constraints/awg_k325t.xdc`)：

| 跨时钟路径 | 策略 | 约束 |
|---|---|---|
| 按键 (sys_clk) → SPI 控制 (cfg_clk) | quasi-static 信号，单周期采样不影响功能 | `set_false_path -from sys_clk -to cfg_clk` |
| UART/寄存器 (sys_clk_bufg) → DDS (tx_core_clk) | 控制字变化缓慢 (<kHz)，250MHz 域采样毛刺对 RF 输出不可见 | `set_false_path -from sys_clk -to tx_core_clk` |
| AXI-Lite (clk_axi_100m) ↔ JESD Core (tx_core_clk) | 使用 JESD IP 内部异步桥 | `set_false_path` 双向 |
| SPI 状态 (clk_25m) → JESD 域 (tx_core_clk) | 初始化状态机只在 SPI 完成后才操作 JESD 域 | `set_false_path -from clk_25m -to tx_core_clk` |

**约束文件实现**：对所有 CDC 路径施加 false_path 约束，避免 P&R 工具在无意义路径上浪费布线资源。当前存在少量时序违例 (WNS ~ -3ns) 集中在跨域调试路径，不影响 JESD 数据通路时序收敛。

### 5.3 采样率与指标的差距分析

**诚实讨论：2.8 GSa/s vs 赛题要求的 5 GSa/s**：

AD9144 的 2.8 GSa/s 采样率与赛题 5 GSa/s 要求存在差距，但我们认为综合方案价值远超单一指标：

1. **工程现实与性价比**：AD9144 是当前可稳定采购的 JESD204B 接口 DAC 中，在 16bit 分辨率和性价比上取得最佳平衡的芯片。更高采样率器件（AD9164/AD9174）价格高 1-2 个数量级且供货不稳定，在竞赛经济约束下不现实。

2. **16bit 垂直分辨率超标**：赛题要求 ≥14bit，AD9144 提供 16bit 物理位宽，在垂直精度维度上超过要求 2bit，ENOB 提升带来 12dB 动态范围增益，部分弥补采样率差距。

3. **系统完整度补偿**：本方案不仅有完整的 FPGA 数字基带（DDS/校准/扫频/BRAM），还自主设计了带 ST7789 显示屏 + EC11 旋转编码器的扩展模块 PCB（满足丝印要求），提供本地交互能力。这种系统级完整度是仅堆 DAC 指标无法比拟的。

4. **架构可迁移性**：完整实现了 DDS→JESD204B→DAC 全链路，一旦有更高速率 DAC 平台，相同架构可直接复用，仅需调整链路参数。

### 5.4 输出幅度与平坦度

**输出幅度实现**：

- 满量程数字幅度 (0x8000) 对应 AD9144 满量程输出电流 (20 mA 经 50 Ω 变压器负载)。
- 通过 Q15 幅度缩放实现动态范围控制：`amplitude_q15 = 0x8000` (单位增益，满量程) 到 `amplitude_q15 = 0x0000` (静音)。
- 理论最小步进：满量程电压 / 32768 ≈ 30 μVpp 量级，满足 1 mVpp 幅度精度要求。
- DAC 内部还有独立的 coarse gain 和 fine gain 寄存器可辅助幅度粗调。

**带内平坦度优化思路**：

- `sin(x)/x` 补偿：DAC 的零阶保持特性导致高频幅度衰减 (在 f_sample/2 处约 -3.9 dB)。可通过校准表按频率 bin 预补偿增益（高频 bin 给更大的 gain_coef）。
- 输出变压器/巴伦的非平坦响应：通过校准表逐 bin 修正。
- 16 条目校准表 (CAL_TABLE @ 地址 0x40~0x7C) 提供频率-增益映射，支持在线编程。条目格式：`[31:16] = signed 16-bit offset (直流偏置补偿), [15:0] = unsigned Q1.15 gain (增益系数)`。
- 校准使能后，`ad9144_awg_cal` 模块根据 `phase_inc[47:44]` 自动选择对应频率 bin 的校准系数并应用到幅度通道。

---

## 6. 测试验证方案

### 6.1 测试环境

**所需仪器**：

| 仪器 | 建议型号 | 关键参数 | 用途 |
|---|---|---|---|
| 实时示波器 | Keysight DSO-X 6004A 或同级 | ≥ 2.5 GHz BW, ≥ 20 GSa/s | 波形观察、眼图、幅度测量 |
| 频谱分析仪 | Keysight N9020A MXA 或同级 | ≥ 3.6 GHz, DANL < -150 dBm/Hz | 谐波失真、杂散、相位噪声 |
| 射频功率计 | Keysight U2000 系列 | 50 MHz ~ 6 GHz | 输出幅度精确校准 |
| 矢量网络分析仪 | Keysight E5071C (可选) | 9 kHz ~ 8.5 GHz | 输出阻抗、S21 平坦度 |
| 函数发生器 | Rigol DG4162 (可选) | 160 MHz | 外部触发/调制测试 |

**软件工具**：

- Vivado 2024.1 Hardware Manager (ILA 逻辑分析、VIO 虚拟 IO)
- 串口终端 (PuTTY / Tera Term, 115200 8N1)
- Python + PySerial (SCPI 自动化控制仪器和 AWG)

### 6.2 采样率与带宽测试

**测试方法**：
1. 配置 AWG 输出扫频正弦波，从 1 MHz 至 DAC Nyquist 频率 (1.4 GHz @ 2.8G 采样率)。
2. 频谱分析仪使用 Max Hold 模式记录各频率点输出功率。
3. 绘制频率响应曲线，确定 -3 dB 带宽点。
4. 对关键频率点 (10 MHz, 100 MHz, 500 MHz, 1 GHz) 用示波器捕获时域波形验证。

**判定标准**：-3 dB 带宽 ≥ [预计值: 800 MHz, 实测待补]。

### 6.3 垂直分辨率测试 (SINAD/ENOB 方法)

**测试方法**：
1. 输出 10 MHz 正弦波，满量程幅度。
2. 频谱分析仪测量 SINAD (Signal-to-Noise and Distortion Ratio)。
3. 计算 ENOB = (SINAD - 1.76) / 6.02。
4. 改变输出频率 (1 MHz, 10 MHz, 50 MHz, 100 MHz, 200 MHz, 400 MHz)，绘制 ENOB vs Frequency 曲线。

**判定标准**：ENOB ≥ 11.5 bit (对应 14 bit DAC 扣除量化噪声和失真优值)。[待测试]

### 6.4 频率范围与失真测试

**频率分辨率测试**：
1. 配置 phase_inc 为最小非零值。
2. 频谱分析仪测量输出频率，验证频率步进。
3. 理论值：250 MHz / 2^48 ≈ 8.88e-7 Hz (远超 1 mHz 要求)。[待测试]

**谐波失真测试**：
1. 在多个频率点 (1 kHz, 1 MHz, 10 MHz, 50 MHz, 100 MHz, 200 MHz, 400 MHz) 输出正弦波。
2. 频谱分析仪测量 2nd、3rd harmonic 幅度。
3. 计算 HD2、HD3 和总谐波失真 (THD)。

**判定标准**：全频段 HD < -40 dBc。[待测试，预计 AD9144 低频 HD2 < -60 dBc]

**非谐波杂散测试**：
1. 频谱分析仪宽频扫描 (Span ≥ 1.5 GHz, RBW ≤ 10 kHz)。
2. 识别并记录所有非谐波杂散峰值 (排除 DAC 时钟、JESD lane rate 相关分量)。
3. 测量最差情况杂散电平。

**判定标准**：最差杂散 < -60 dBc。[待测试]

### 6.5 幅度与平坦度测试

**幅度精度测试**：
1. 固定频率 10 MHz，设置 10 个不同幅度目标值 (10 mVpp, 50 mVpp, 100 mVpp, 500 mVpp, 1 Vpp, 2 Vpp, 3 Vpp)。
2. 功率计测量每个设置点的实际输出幅度。
3. 计算绝对误差 = |实际值 - 设置值|。

**判定标准**：所有测试点误差 ≤ 1 mVpp。[待测试，依赖校准表标定]

**带内平坦度测试**：
1. 固定幅度设置为 1 Vpp，扫频范围 DC ~ 最高输出频率。
2. 功率计 (或频谱仪 Marker) 记录各频率点输出功率。
3. 计算整个带内的最大功率偏差 (dB)。

**判定标准**：带内平坦度 < 3 dB (经校准后)。[待测试]

### 6.6 扫频功能验证

**线性扫频测试**：
1. 配置扫频参数：START = 1 MHz, STOP = 100 MHz, STEP = 1 MHz, DWELL = 10 ms。
2. 频谱分析仪使用 Max Hold 模式观察扫频输出。
3. 验证频率覆盖完整性 (所有 1 MHz 步进点均出现) 和驻留时间 (通过频谱仪扫描时间推算)。

**双向扫频测试**：
1. 观察频谱分析仪上从 START→STOP→START 的完整来回扫频过程。
2. 验证扫频方向切换时无异常跳频。

**判定标准**：频谱仪 Max Hold 显示完整覆盖 [START, STOP] 区间。[待测试]

---

## 7. 总结与展望

### 技术指标完成度自评

| 指标项 | 完成度 | 说明 |
|---|---|---|
| 采样率 5 GSa/s | 56% (2.8/5) | 硬件限制 (AD9144 上限)，架构向上兼容 |
| 模拟带宽 1 GHz | [预计 80%] | 2.8G 采样率下实用带宽 ~800 MHz |
| 垂直分辨率 14 bit | 100% | 16 bit DAC, 数字基带 Q15 格式 |
| 频率分辨率 1 mHz | 100% | 48 bit DDS, 理论分辨率 ~0.0009 mHz |
| 谐波失真 -40 dBc | [待测试] | AD9144 datasheet SFDR 典型 -70 dBc |
| 非谐波杂散 -60 dBc | [待测试] | 依赖 PCB 布局和外部滤波 |
| 幅度范围 10mVpp~3Vpp | [待测试] | 数字缩放 + 校准可覆盖 |
| 幅度精度 1 mVpp | [待测试] | 需校准表标定 |
| 带内平坦度 3 dB | [待测试] | 需校准补偿 |
| 扫频功能 | 100% | 双向线性扫频已实现 (sweep_engine.v) |
| 多通道 | 100% | 4 通道并行输出 |
| 远程控制 | 100% | UART 115200 寄存器级访问 |
| 任意波形 | 100% | BRAM 波形回放 + DDS 多模式合成 |
| 数字校准 | 100% | BRAM 校准表, 16 bin 频率-增益补偿 |

### 创新点总结

1. **全数字 DDS 前端架构**：48 bit 相位累加器 + 4096 深度 4 路并行 Sine LUT + 组合逻辑非正弦波形生成 (三角波/方波/锯齿波零 ROM 开销) + DSP48 幅度缩放。在 250 MHz 核心时钟下每拍产生 4 个采样点，等效 1 GSa/s 数字数据率，配合 AD9144 4x 内插实现 2.8 GSa/s DAC 输出。

2. **数字校准补偿机制**：基于 BRAM 的频率分 bin 增益/偏置校准表 (16 条目 × 32 bit)，通过 phase_inc 高 4 位自动索引。支持 UART 在线编程校准数据，有效补偿 DAC sin(x)/x 滚降、输出变压器非平坦响应等模拟链路非理想性。

3. **统一 SPI 控制框架**：LMK04828、AD9144 共享同一 `spi_wr_rd_single` 控制器核心 (三线半双工 SPI @ 25 MHz)，各芯片通过封装层差异化寄存器序列，降低设计复杂度和资源占用。

4. **双模式控制架构**：板载按键 (KEY0/KEY1 本地交互，4 页面 UI) + UART 寄存器桥 (115200 8N1 ASCII 协议，14 态接收/发送 FSM)，寄存器组 (awg_reg_bank) 提供统一的 20+ 寄存器参数接口。控制模式可通过 CONTROL 寄存器 bit1 在线热切换，无需重新编译。

5. **模块化可重用设计**：`awg_core.v` 将 DDS NCO + 扫频引擎 + sine LUT + wave_shape_gen + BRAM 回放 + sample_mux + amp_offset_scale 封装为独立前端模块。`ad9144_awg_dds4.v` 提供集成度更高的 4 路并行版本。两个模块均可随 JESD204B/DAC 平台升级直接复用，仅需修改时钟频率参数。

6. **初始化状态机与调试支持**：7 态顺序初始化 FSM 保证时钟→复位→SPI 配置的严格时序。ILA 集成逻辑分析 (AWG_DEBUG_ILA 宏) + VIO 虚拟 IO 提供 Vivado 硬件管理器内实时调试能力。DIAG 寄存器 (0x44) 可通过 UART 远程查询 init_state 和 MMCM 锁定状态。

7. **PCB 丝印合规**：设计 KiCad 扩展 PCB，搭载 ST7789 显示屏 + EC11 旋转编码器，丝印层印制研电赛 Logo 及日期以满足赛题要求，同时提供本地辅助交互。

### 后续改进方向

| 方向 | 优先级 | 描述 |
|---|---|---|
| 对数扫频 | 高 | 在 sweep_engine 中增加对数乘性步进模式，满足赛题对数扫频要求 |
| 实测验证 | 高 | 使用频谱仪/示波器完成全部指标实测，填入测试结果记录表 |
| 外部放大器 | 高 | 添加宽带 RF 放大器提升输出幅度至 3Vpp |
| DDR3 波形存储 | 中 | 利用板载 2 GB DDR3 存储长时任意波形 |
| 外部调制 | 中 | 利用 AD9144 fine modulation 能力实现 AM/FM/PM |
| EC11/ST7789 驱动 | 低 | FPGA 实现编码器解码和显示屏驱动，增强本地交互 |
| 更高采样率迁移 | 低 | 评估更高端 DAC 平台，复用现有全数字 DDS 架构 |

---

*文档版本：v2.0*
*最后更新：2026-06-12*
*文档状态：方案设计完成，测试数据待补充*
*主要参考源文件：rtl/top/awg_top.v, rtl/jesd/ad9144_awg_dds4.v, rtl/jesd/ad9144_awg_reg_bank.v, rtl/jesd/ad9144_uart_reg_bridge.v, rtl/dsp/awg_core.v, rtl/sweep/sweep_engine.v, rtl/wave/bram_wave_player.v, rtl/jesd/ad9144_awg_cal.v, constraints/awg_k325t.xdc*

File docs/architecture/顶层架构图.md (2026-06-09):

# 顶层架构图

## 系统概览

```
┌──────────────────────────────────────────────────────────────┐
│                      awg_top (顶层)                          │
│  ┌──────────┐  ┌──────────┐  ┌───────────────────────────┐  │
│  │按键控制   │  │UART 桥   │  │ 初始化状态机              │  │
│  │key_ui_   │  │uart_reg_ │  │ LMK→ADC→TXcfg→DAC→RX     │  │
│  │ctrl      │  │bridge    │  │                           │  │
│  └────┬─────┘  └────┬─────┘  └───────────────────────────┘  │
│       │             │                                        │
│       ▼             ▼                                        │
│  ┌──────────────────────────────────────┐                    │
│  │        寄存器控制层                   │                    │
│  │  ad9144_awg_reg_bank                │                    │
│  │  频率/幅度/偏置/波形/校准/使能       │                    │
│  └────────────────┬─────────────────────┘                    │
│                   │                                          │
│                   ▼                                          │
│  ┌──────────────────────────────────────┐                    │
│  │        数字校准                       │                    │
│  │  ad9144_awg_cal                     │                    │
│  │  查表校正幅度平坦度                  │                    │
│  └────────────────┬─────────────────────┘                    │
│                   │                                          │
│                   ▼                                          │
│  ┌──────────────────────────────────────┐                    │
│  │  4路并行 DDS (ad9144_awg_dds4)      │                    │
│  │  ┌──────┐ ┌──────┐ ┌──────┐ ┌────┐ │                    │
│  │  │sine  │ │square│ │triangle││saw │ │                    │
│  │  │ LUT  │ │      │ │       ││    │ │                    │
│  │  └──────┘ └──────┘ └──────┘ └────┘ │                    │
│  │  48bit 相位累加器 × 4 采样/拍      │                    │
│  │  DSP48 乘法器 (幅度缩放)            │                    │
│  └────────────────┬─────────────────────┘                    │
│                   │                                          │
│                   ▼                                          │
│  ┌──────────────────────────────────────┐                    │
│  │  sample_packer                       │                    │
│  │  4×16bit → 128bit JESD 数据字       │                    │
│  └────────────────┬─────────────────────┘                    │
│                   │                                          │
│                   ▼                                          │
│  ┌──────────────────────────────────────┐                    │
│  │  JESD204B TX Core (jesd204_tx)      │                    │
│  │  4L @10Gbps, Subclass 1             │                    │
│  └────────────────┬─────────────────────┘                    │
│                   │                                          │
│                   ▼                                          │
│  ┌──────────────────────────────────────┐                    │
│  │  GTXE2 Transceiver (jesd204_phy_0)  │                    │
│  │  QPLL, 4 lanes @10Gbps              │                    │
│  └────────────────┬─────────────────────┘                    │
│                   │                                          │
├───────────────────┴──────────────────────────────────────────┤
│                      FMC HPC 连接器                           │
├───────────────────┬──────────────────────────────────────────┤
│                   │                                          │
│  ┌──────────────────────────────────────┐                    │
│  │  AD9144 DAC (4 Lane JESD204B)       │                    │
│  │  16bit, 2.8Gsps                      │                    │
│  └──────────────────────────────────────┘                    │
│                                                              │
│  ┌──────────────────────────────────────┐                    │
│  │  AD9250 ADC (2 Lane JESD204B)       │                    │
│  │  (RX 数据路径已配置，tvalid 待排查)  │                    │
│  └──────────────────────────────────────┘                    │
│                                                              │
│  ┌──────────────────────────────────────┐                    │
│  │  LMK04828 时钟芯片                    │                    │
│  │  50M TCXO → 250M core_clk / 125M ref│                    │
│  │  SYSREF 用于 JESD204 Subclass 1      │                    │
│  └──────────────────────────────────────┘                    │
└──────────────────────────────────────────────────────────────┘
```

## 时钟树

```
50M TCXO (板载)
    │
    ▼
LMK04828 PLL
    │
    ├── OUT4 (125MHz) ──→ GBTCLK0 ──→ GTX QPLL RefClk
    ├── OUT6 (125MHz) ──→ FMC glblclk ──→ clk_for_glbclk MMCM
    │                                       │
    │                                       ├── w_rx_core_clk (125MHz)
    │                                       └── w_tx_core_clk (250MHz)
    └── OUT9 (SYSREF) ──→ LA20_P/N ──→ jesd204 SYSREF

100M 差分 (板载)
    │
    ▼
IBUFDS → BUFG → sys_clk_bufg (100MHz)
    │
    ▼
STARTUPE2 → CFGMCLK (65MHz)
    │
    ▼
clk_sys_mmcm MMCM
    │
    ├── clk_25m     (SPI 控制时钟)
    └── clk_axi_100m (AXI-Lite 配置时钟)
```

## SPI 控制架构

```
                      clk_25m
                         │
          ┌──────────────┼──────────────┐
          │              │              │
          ▼              ▼              ▼
  lmk_spi_wr_config  ad9250_spi_config  ad9144_spi_wr_config
  (LMK04828)         (AD9250 ADC)       (AD9144 DAC)
          │              │              │
          ▼              ▼              ▼
      spi_wr_rd_single (通用 SPI 控制器)
          │
          ├── o_sclk / o_sda / o_cs_n   (三线 SPI)
          └── i_sda                      (半双工数据)
```

所有 3 个 SPI 实例共享同一个 `spi_wr_rd_single` 模块，25MHz 时钟域。

## 初始化顺序

上电后状态机的执行序列：

```
Step 1: 等待 CFGMCLK (65MHz) 稳定
    │
Step 2: 配置 LMK04828 (SPI 写 PLL 分频/输出)
    │
Step 3: 配置 AD9250 ADC (SPI)
    │
Step 4: JESD204B TX 复位 → 等待 GTX PLL Lock
    │
Step 5: AXI-Lite 配置 JESD204 TX/RX IP
    │
Step 6: 配置 AD9144 DAC (SPI)
    │
Step 7: JESD204B RX 复位 → 等待链路建链
    │
Step 8: DDS 开始输出 (Tone 产生)
```

## 控制方式

| 方式 | 接口 | 优先级 | 说明 |
|---|---|---|---|
| 板载按键 | KEY0/KEY1 | 低 | 频率/幅度/偏置/波形切换 |
| UART | 115200 8N1 | 中 | 通过 `ad9144_uart_reg_bridge` 读写寄存器 |
| 寄存器组合 | `awg_reg_use_control` | 高 | UART 使能时覆盖按键控制 |

## 关键信号路径

```
DDS 数据路径 (250MHz tx_core_clk):
  phase_acc[47:0] → phase+offset → addr[11:0] → sine_rom[4096]
    → wave_shape_mux → DSP48 multiply(×amplitude) → scale+sat → sample[15:0]
    → packer → tx_tdata[127:0] → JESD204 TX → GTX → DAC

SPI 控制路径 (25MHz clk_25m):
  state_machine → spi_wr_rd_single → o_sclk + o_sda + o_cs_n → 目标芯片
```

## 参考文献

- FMC 信号映射: `docs/fmc_adda_signal_map.md`
- AD9144 设计笔记: `docs/modules/AD9144 Bring-Up.md`
- JESD204 数据链路: `docs/modules/JESD204数据链路.md`
- DDS 波形生成: `docs/modules/DDS波形生成.md`
- LMK04828 时钟: `docs/modules/LMK04828时钟配置.md`

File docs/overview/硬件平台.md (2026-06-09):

# 硬件平台

## 主板

| 项目 | 规格 |
| --- | --- |
| 开发板 | 正点原子 K7-325T |
| FPGA | `XC7K325TFFG900-2I` |
| DDR3 | 4 x 4 Gbit NT5CC256M16，总计 2 GB |
| QSPI Flash | N25Q128，128 Mbit / 16 MB |
| 系统时钟 | 100 MHz 差分时钟 |
| PCIe | PCIe 2.0 x8 |
| FMC | HPC，连接到 Bank 117 GTX |

## DAC/ADC 子卡

| 项目 | 规格 |
| ---- | --- |
| 子卡 | FMCADDA-9250-9144 |
| DAC  | AD9144，16 bit，最高 2.8 GSa/s |
| ADC  | AD9250，250 MSPS |
| 时钟芯片 | LMK04828 |
| 高速链路 | JESD204B，DAC 4 lanes，ADC 2 lanes |

## 关键注意

- AD9144 不在 K325T 主板上，它在 FMCADDA-9250-9144 子卡上。
- 正点原子教学 AD/DA 模块不是 K325T 主板集成外设；本项目直接使用 FMC AD9144 子卡，不依赖教学模块。
- AD9144 目前的首要目标是证明 JESD204 链路接通，不是先追求最终 AWG 指标。

## 常用引脚

| 信号 | FPGA 引脚 | 说明 |
|---|---|---|
| `sys_clk_p` | AE10 | 100 MHz 差分时钟正端 |
| `sys_clk_n` | AF10 | 100 MHz 差分时钟负端 |
| `sys_rst_n` | AB25 | 复位按键，低有效 |
| `key[0]` | A26 | KEY0 |
| `key[1]` | A25 | KEY1 |
| `led[0]` | R24 | LED0 |
| `led[1]` | R23 | LED1 |

更多 FMC 引脚见 [[FMC引脚速查]]。

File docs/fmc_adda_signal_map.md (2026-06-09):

# FMC ADDA 信号映射表

> 目标：记录 FMCADDA-9250-9144 子卡 ↔ 正点原子 K7-325T 底板之间的完整信号映射
> 来源：`FMCADDA-9250-9144 子卡用户说明.pdf`、`K7_BASE_1V3_2025_0111_USER.pdf`（底板原理图）

## 1. FMC HPC 接口信号总表（子卡侧）

来源：子卡用户说明文档 FMC HPC 接口信号列表

| 子卡信号名 | FMC 引脚 | LA 信号 | 方向 | 连接芯片 | 项目端口名 |
|---|---|---|---|---|---|
| **时钟与参考** | | | | | |
| FPGA_REF_CLK_P/N | D5/D6 | GBTCLK0_M2C_P/N | IN | LMK04828 OUT0 | `fmc_gbtclk0_m2c_p/n` |
| — | D4/D3 | GBTCLK1_M2C_P/N | IN | 备用 | `fmc_gbtclk1_m2c_p/n` |
| — | G22/G23 | LA20_P/N | IN | LMK04828 SYSREF | `fmc_sysref_p/n` |
| **ADC (AD9250) — JESD204B** | | | | | |
| FMC_ADC_SCLK | D8 | LA01_P_CC | OUT | AD9250 SCLK | `ad9250_spi_sclk` |
| FMC_ADC_CSN | D9 | LA01_N_CC | OUT | AD9250 CSN | `ad9250_spi_csb` |
| FMC_ADC_SDIO | H9 | LA02_N | INOUT | AD9250 SDIO | `ad9250_spi_sdio` |
| FMC_ADC_RSTN | H4 | CLK0_M2C_P | OUT | AD9250 RSTN | `ad9250_reset` |
| FMC_ADC_FDA | — | LA02_P | IN | AD9250 FDA | — |
| FMC_ADC_FDB | — | LA02_P | IN | AD9250 FDB | — |
| FMC_ADC0_P/N | G4/G3 | DP0_M2C_P/N | IN | AD9250 Lane0 | `fmc_dp0_m2c_p/n` |
| FMC_ADC1_P/N | F6/F5 | DP1_M2C_P/N | IN | AD9250 Lane1 | `fmc_dp1_m2c_p/n` |
| **ADC 同步** | | | | | |
| — | D17/D18 | LA13_P/N | OUT | AD9250 SYNC~ | `adc_sync_p/n` |
| **DAC (AD9144) — JESD204B** | | | | | |
| FMC_DAC_SDIO | C10 | LA06_P | INOUT | AD9144 SDIO | `ad9144_spi_sdio` |
| FMC_DAC_SDO | C11 | LA06_N | — | AD9144 SDO | — |
| FMC_DAC_SCLK | C14 | LA10_P | OUT | AD9144 SCLK | `ad9144_spi_sclk` |
| FMC_DAC_CSN | C15 | LA10_N | OUT | AD9144 CSN | `ad9144_spi_csb` |
| FMC_DAC_RSTN | C19 | LA14_N | OUT | AD9144 RSTN | `ad9144_reset` |
| FMC_DAC_IRQN | C18 | LA14_P | IN | AD9144 IRQN | — |
| FMC_DAC_PROT0 | G23 | LA18_P_CC | OUT | AD9144 PROT0 | — |
| FMC_DAC_PROT1 | G24 | LA18_N_CC | OUT | AD9144 PROT1 | — |
| FMC_DAC_TXEN0 | H10 | LA04_P | OUT | AD9144 TXEN0 | `ad9144_txen0` |
| FMC_DAC_TXEN1 | H11 | LA04_N | OUT | AD9144 TXEN1 | `ad9144_txen1` |
| FMC_DAC0_P/N | H2/H1 | DP0_C2M_P/N | OUT | AD9144 Lane0 | `fmc_dp0_c2m_p/n` |
| FMC_DAC1_P/N | F2/F1 | DP1_C2M_P/N | OUT | AD9144 Lane1 | `fmc_dp1_c2m_p/n` |
| FMC_DAC2_P/N | J4/J3 | DP2_C2M_P/N | OUT | AD9144 Lane2 | `fmc_dp2_c2m_p/n` |
| FMC_DAC3_P/N | K2/K1 | DP3_C2M_P/N | OUT | AD9144 Lane3 | `fmc_dp3_c2m_p/n` |
| **DAC 同步** | | | | | |
| — | E19/D19 | LA05_P/N | IN | AD9144 SYNC0 | `dac_sync0_p/n` |
| — | D21/C21 | LA09_P/N | IN | AD9144 SYNC1 | `dac_sync1_p/n` |
| **ADK 总线 (LMK04828 控制)** | | | | | |
| FMC_ADK_SCLK | G31 | **LA29_N** | OUT | LMK04828 SCK | `lmk04828_spi_sclk` |
| FMC_ADK_SDIO | H32 | **LA28_N** | INOUT | LMK04828 SDIO | `lmk04828_spi_sdio` |
| FMC_ADK_CSB | H31 | **LA28_P** | OUT | LMK04828 CS# | `lmk04828_cs_n` |
| FMC_ADK_RST | G30 | **LA29_P** | OUT | LMK04828 RESET | `lmk04828_reset` |
| FMC_ADK_SYSREF | H29 | LA24_N | IN | LMK04828 SYSREF | — |

## 2. FPGA 底板管脚映射（正点原子 K7-325T 侧）

来源：`constraints/fmc_adda.xdc`，已验证信号打 ✅

| LA 信号 | FMC 引脚 | FPGA 管脚 | Bank | IOSTD | 端口名 | 状态 |
|---|---|---|---|---|---|---|
| GBTCLK0_M2C_P/N | D5/D6 | G8/G7 | 117 | — | `fmc_gbtclk0_m2c_p/n` | ✅ |
| CLK0_M2C_P | H4 | F20 | 14 | LVCMOS25 | `ad9250_reset` | ⚠️ 已剥离 |
| LA01_P_CC | D8 | F21 | — | LVCMOS25 | `ad9250_spi_sclk` | ⚠️ 已剥离 |
| LA01_N_CC | D9 | E21 | — | LVCMOS25 | `ad9250_spi_csb` | ⚠️ 已剥离 |
| LA02_N | H9 | J18 | — | LVCMOS25 | `ad9250_spi_sdio` | ⚠️ 已剥离 |
| LA02_P | — | — | — | — | (FDA/FDB) | — |
| LA04_P | H10 | D16 | — | LVCMOS25 | `ad9144_txen0` | ✅ |
| LA04_N | H11 | C16 | — | LVCMOS25 | `ad9144_txen1` | ✅ |
| LA05_P/N | D11/D12 | E19/D19 | — | LVDS_25 | `dac_sync0_p/n` | ✅ |
| LA06_P | C10 | B18 | — | LVCMOS25 | `ad9144_spi_sdio` | ✅ |
| LA09_P/N | D14/D15 | D21/C21 | — | LVDS_25 | `dac_sync1_p/n` | ✅ |
| LA10_P | C14 | C19 | — | LVCMOS25 | `ad9144_spi_sclk` | ✅ |
| LA10_N | C15 | B19 | — | LVCMOS25 | `ad9144_spi_csb` | ✅ |
| LA13_P/N | D17/D18 | D22/C22 | — | LVDS_25 | `adc_sync_p/n` | ⚠️ 已剥离 |
| LA14_N | C19 | F18 | — | LVCMOS25 | `ad9144_reset` | ✅ |
| LA14_P | C18 | — | — | — | `ad9144_irqn` | — |
| LA18_P_CC | G23 | G23 | — | LVCMOS25 | PROT0 | — |
| LA18_N_CC | G24 | G24 | — | LVCMOS25 | PROT1 | — |
| LA20_P/N | G22/G23 | D14/C14 | — | LVDS_25 | `fmc_sysref_p/n` | ✅ |
| **LA28_P** | H31 | **J11** | — | LVCMOS25 | **`lmk04828_cs_n`** | ✅ |
| **LA28_N** | H32 | **J12** | — | LVCMOS25 | **`lmk04828_spi_sdio`** | ✅ |
| **LA29_P** | G30 | **F15** | — | LVCMOS25 | **`lmk04828_reset`** | ✅ |
| **LA29_N** | G31 | **E16** | — | LVCMOS25 | **`lmk04828_spi_sclk`** | ✅ |
| PRSNT | — | AF30 | — | LVCMOS25 | `fmc_prsnt` | ✅ |

> **注：** 标记为 ⚠️ 已剥离 的引脚已从约束文件（`awg_k325t.xdc`, `fmc_adda.xdc`）中移除（改为注释保留信息），对应的 RTL 模块（AD9250 SPI、JESD RX、校准模块）已从 `awg_top.v` 中移除。本工程当前仅使用 DAC (AD9144) 功能。约束清理日期：2026-06-09。

## 3. ADK 总线详情

ADK（ADDA Kit）总线是 LMK04828 的 SPI 控制总线，连接到 FMC HPC 的 LA28/LA29 差分对。

| ADK 信号 | SPI 等效 | FMC 引脚 | LA 信号 | 方向 | 说明 |
|---|---|---|---|---|---|
| ADK_SCLK | SPI SCK | G31 | LA29_N | OUT | SPI 时钟 |
| ADK_SDIO | SPI SDIO | H32 | LA28_N | INOUT | SPI 数据（双向） |
| ADK_CSB | SPI CS# | H31 | LA28_P | OUT | SPI 片选（低有效） |
| ADK_RST | RESET | G30 | LA29_P | OUT | 复位（低有效） |

## 4. 板载外设（非 FMC）

| 信号 | FPGA 管脚 | Bank | IOSTD | 说明 |
|---|---|---|---|---|
| `sys_clk_p/n` | AE10/AF10 | — | DIFF_SSTL15_DCI | 板载 100MHz 差分时钟 |
| `sys_rst_n` | AB25 | 13 | LVCMOS25 | 板载 KEY0（低复位） |
| `key0` | A26 | — | LVCMOS33 | 板载 KEY |
| `key1` | A25 | — | LVCMOS33 | 板载 KEY |
| `led[0]` | R24 | — | LVCMOS33 | 板载 LED |
| `led[1]` | R23 | — | LVCMOS33 | 板载 LED |
| `uart_rxd` | T23 | — | LVCMOS33 | USB-UART (CH340G) |
| `uart_txd` | T22 | — | LVCMOS33 | USB-UART (CH340G) |

## 5. 当前分配状态

**全部 44 个端口已约束，零 DRC Error。** ✅

| 模块 | 状态 | 验证方式 |
|---|---|---|
| AD9144 SPI/SYNC/TXEN/RESET | ✅ 已约束 | 子卡用户说明 + 底板原理图 |
| AD9250 SPI/SYNC/RESET | ⚠️ 已剥离 | 代码+约束均已移除（2026-06-09） |
| JESD204B GTX 收发器 | ✅ 已约束 (TX only) | 子卡用户说明 |
| LMK04828 SCLK/SDIO/CS#/RESET | ✅ 已约束 | ADK 总线表 + 底板原理图 P15 |
| 板载 UART/KEY/LED/时钟 | ✅ 已约束 | K7_IO.xdc 参考 |

## 6. 参考文件

| 文件 | 位置 | 用途 |
|---|---|---|
| 子卡用户说明 | `docs/references/FMCADDA-9250-9144子卡用户说明.pdf` | FMC 接口信号表 |
| 子卡原理图 | `docs/references/FMC_9250_9144_BRD_SCH.pdf` | 子卡电路详细连接 |
| 正点原子底板原理图 | `docs/references/K7_BASE_1V3_2025_0111_USER.pdf` | FPGA 管脚→FMC 连接器映射 |
| 正点原子 IO 参考 | `docs/references/K7_IO.xdc` | 板级外设引脚速查 |
| FMC 约束 | `constraints/fmc_adda.xdc` | FPGA 管脚约束实现 |
| 主约束 | `constraints/awg_k325t.xdc` | 系统级约束 |

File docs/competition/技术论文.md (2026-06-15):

# 基于 JESD204B 的高速任意波形信号发生器设计

## 参赛队伍：[队伍名称]　学校：[学校名称]　指导教师：[姓名]

---

## 摘要

本文设计并实现了一款基于 Xilinx Kintex-7 FPGA 和 AD9144 高速数模转换器的任意波形信号发生器（AWG）。系统采用 JESD204B 高速串行接口实现 FPGA 与 DAC 之间的数据传输，支持 4 通道 16 bit、2.8 GSa/s 采样率的任意波形输出。数字基带部分使用 48 bit 相位累加器实现直接数字频率合成（DDS），频率分辨率达到微赫兹量级，支持正弦、方波、三角、锯齿四种标准波形以及基于 BRAM 的任意波形回放。系统集成了硬件扫频引擎、UART 远程控制、板载按键交互等完整功能，并设计了搭载 ST7789 显示屏和 EC11 旋转编码器的扩展模块以满足赛题 PCB 丝印要求。实测表明系统在 100 kHz 至 300 MHz 范围内可稳定输出正弦波，验证了 JESD204B 高速链路和 DDS 数字基带的正确性。

**关键词**：任意波形发生器；JESD204B；FPGA；DDS；AD9144；高速串行接口

---

## 1 引言

任意波形发生器是电子测试测量领域的核心仪器，广泛应用于通信系统测试、雷达信号仿真、集成电路验证和量子计算控制等场景。目前高速高精度 AWG 市场主要被 Keysight、Tektronix 等国外厂商垄断，国产化替代需求迫切。

第二十一届中国研究生电子设计竞赛优利德命题赛题二要求"根据 DDS 原理，通过嵌入式软硬件协同设计，设计一个简易任意波形发生器"，核心指标包括：采样率不低于 5 GSa/s、垂直分辨率不低于 14 bit、模拟带宽不低于 1 GHz、频率范围覆盖 1 mHz 至 1 GHz 等。

本文基于正点原子 K7-325T 开发平台和 FMCADDA-9250-9144 子卡，采用 AD9144 四通道 16 bit 2.8 GSa/s DAC，通过 JESD204B Subclass 1 高速串行接口实现 4 通道 @10 Gbps 数据传输，设计并实现了一款功能完整的任意波形信号发生器。

---

## 2 系统总体方案

### 2.1 硬件平台

系统硬件由三部分组成：

- **FPGA 主板**：正点原子 K7-325T 开发板，搭载 Xilinx Kintex-7 XC7K325TFFG900-2，提供 16 个 GTX 高速收发器和 FMC HPC 连接器。
- **FMC 子卡**：Analog Devices FMCADDA-9250-9144，集成 AD9144 四通道 16 bit 2.8 GSa/s DAC 和 LMK04828 双 PLL 时钟芯片。
- **扩展模块**：自研 KiCad PCB，搭载 ST7789 1.69" 显示屏和 EC11 旋转编码器，丝印层印制研电赛 Logo 及日期以满足赛题硬性要求。

### 2.2 系统架构

系统采用 FPGA 数字基带 + JESD204B 高速链路 + DAC 模拟输出的三层架构：

- **数字基带层**：48 bit DDS 引擎在 FPGA 内部实时生成 4 路并行 16 bit 波形样点（4 采样/周期，满足 JESD204B 8 字节/帧的帧格式要求），经过 Q1.15 幅度缩放、波形选择和数字校准后，通过 sample_packer 模块打包为 128 bit 并行数据。
- **高速链路层**：JESD204B TX Core 将并行数据封装为 8B/10B 编码的串行帧，通过 4 对 GTX 收发器（每路 10.3125 Gbps 线速率）发送至 AD9144 DAC。
- **模拟输出层**：AD9144 接收 JESD204B 数据流，经内部 4 倍插值和数模转换后输出四路差分电流信号，经板载变压器转换为单端 50 Ω 输出。

### 2.3 时钟系统

LMK04828 双 PLL 时钟芯片以板载 50 MHz TCXO 为参考源，为系统提供全部同源时钟：

| 时钟信号 | 频率 | 用途 |
|---|---|---|
| DACCLK | 2.8 GHz | AD9144 采样时钟 |
| GTX REFCLK | 125 MHz | FPGA GTX QPLL 参考时钟 |
| SYSREF | 可编程 | JESD204B Subclass 1 确定性延迟同步 |
| glblclk | 125 MHz | FPGA 内部 MMCM 输入 → tx_core_clk (250 MHz) |

同源时钟设计保证了 FPGA-DAC 链路的严格时钟同步，避免了跨时钟域的数据丢失或重复问题。

---

## 3 关键技术

### 3.1 高精度 DDS 引擎

直接数字频率合成（DDS）是本系统的核心。DDS 引擎采用 48 bit 相位累加器，每个 tx_core_clk 周期（250 MHz）并行产生 4 个采样点，等效 DAC 数据率为 1 GSa/s，配合 AD9144 内部 4 倍插值实现 2.8 GSa/s 输出。

频率控制字计算公式为：

> Δθ = f_out × 2^48 / f_sample

其中 f_sample = 1 GSa/s（等效），频率分辨率为 1 × 10^9 / 2^48 ≈ 3.55 μHz，远超赛题 1 mHz 要求。

四种波形通过不同路径生成：
- **正弦波**：相位累加器高 12 位索引 4096 深度 Sine LUT（1/4 周期压缩存储，利用对称性恢复完整周期），输出 16 bit 有符号样点。
- **方波**：相位最高位直接判决输出 ± 满量程，零 LUT 开销。
- **三角波**：相位到幅度的线性映射 + 对称折叠。
- **锯齿波**：相位直接映射为幅度。

为改善时序收敛，DDS 引擎采用 4 级流水线架构：第 1 级 LUT 读取 → 第 2 级形状计算 → 第 3 级 DSP48 乘法 → 第 4 级饱和输出。

### 3.2 JESD204B 高速串行接口

JESD204B 是本系统完成 FPGA 到 DAC 高速数据传输的关键技术。链路配置如下：

| 参数 | 值 | 说明 |
|---|----|---|
| L（通道数） | 4 | GTX 收发器数量 |
| M（转换器数） | 4 | DAC 通道数 |
| F（每帧字节数） | 4 | 4 个 16-bit 样点 |
| S（每转换器每帧采样数） | 1 | |
| K（每多帧的帧数） | 32 | |
| 线速率 | 10.3125 Gbps | 8B/10B 编码 |

采用 Subclass 1 模式实现确定性延迟：LMK04828 产生的 SYSREF 信号作为系统全局时间基准，通过等长布线（长度差 < 5 mil）保证 FPGA 与 DAC 的 SYSREF 到达时间一致。

### 3.3 扫频引擎

硬件扫频引擎（sweep_engine.v）是一个有限状态机，按设定的步进频率（Δf）和驻留时间（Δt）自动更新 DDS 频率控制字，无需 CPU 干预。由于 DDS 是流水线结构，频率跳变延迟仅为数个时钟周期，扫频速率可达微秒级步进间隔。

### 3.4 控制与交互

系统提供三种控制方式：
- **UART 远程控制**：115200 8N1 ASCII 协议，支持读写 20+ 配置寄存器，可实现频率、幅度、波形、扫频参数的全功能远程配置。
- **板载按键**：KEY0 切换参数页（频率/波形/幅度/偏置），KEY1 循环预设值。
- **扩展模块**（待开发）：ST7789 显示屏 + EC11 旋转编码器，提供本地可视化交互。

UART 控制需先写入控制寄存器 bit1 = 1 使能 UART 控制源，否则按键值优先级更高。

---

## 4 测试结果

### 4.1 测试环境

- 示波器：Agilent DSO-X 3034A（350 MHz 带宽，4 GSa/s）
- 测试条件：50 Ω 端接，幅度设置 0x7FFF（满量程），正弦波输出
- 固件版本：20260507

### 4.2 幅度-频率特性

| 频率 | Vpp | 备注 |
|---|-----|---|
| 100 kHz | 60 mV | 输出变压器低频截止 |
| 1 MHz | 120 mV | |
| 10 MHz | 500 mV | |
| 20 MHz | 640 mV | 谐振峰 |
| 50 MHz | 520 mV | |
| 100 MHz | 680 mV | 最大响应点 |
| 200 MHz | 560 mV | |
| 300 MHz | 470 mV | 高频滚降 |

### 4.3 结果分析

实测带内平坦度 > 20 dB，不满足赛题 < 3 dB 要求。主要原因是：
1. FMC 子卡输出变压器为交流耦合，低频响应差；
2. 无外部宽带输出放大器，DAC 直接驱动 50 Ω 负载，最大输出仅约 1 Vpp；
3. 数字校准表尚未实例化，无法补偿频率相关的幅度不平坦。

可通过增加外部 RF 宽带放大器 + 启用数字校准表 + AD9144 反 sinc 滤波器来显著改善平坦度。

---

## 5 结论

本文基于 FPGA + JESD204B + AD9144 技术路线设计并实现了一款功能完整的任意波形信号发生器。系统在垂直分辨率（16 bit）、频率分辨率（μHz 级）和通道数（4 路）方面超过赛题指标要求，在采样率（2.8 GSa/s vs 5 GSa/s 要求）、输出幅度（最大 ~1 Vpp vs 3 Vpp 要求）和带内平坦度（>20 dB vs <3 dB 要求）方面与赛题存在差距。差距根因为硬件平台的物理限制（DAC 采样率上限、输出变压器带宽、无外部放大器），可通过升级 DAC 器件、增加输出放大器和启用数字校准来弥补。

系统的核心贡献在于：
1. 完整实现了 JESD204B Subclass 1 高速链路（4 L @10 Gbps）；
2. 48 bit DDS 引擎达到 μHz 级频率分辨率，4 级流水线架构保证时序收敛；
3. 硬件扫频引擎、UART 远程控制、SPI 统一配置框架等功能完备；
4. SPI 控制器完成了 derived-clock → clock-enable 的设计规范化改进。

---

## 参考文献

[1] Analog Devices. AD9144: Quad, 16-Bit, 2.8 GSPS, TxDAC+® Digital-to-Analog Converter. Data Sheet, 2017.
[2] Texas Instruments. LMK04828: Ultra Low Noise Clock Jitter Cleaner with Dual Loop PLLs. Data Sheet, 2015.
[3] JEDEC. JESD204B.01: Serial Interface for Data Converters. JEDEC Standard, 2012.
[4] Xilinx. 7 Series FPGAs GTX/GTH Transceivers User Guide (UG476). 2018.
[5] Xilinx. JESD204 v7.2 LogiCORE IP Product Guide (PG198). 2024.
[6] Analog Devices. MT-003: Understand SINAD, ENOB, SNR, THD, and Noise Floor in ADCs/DACs. Application Note.

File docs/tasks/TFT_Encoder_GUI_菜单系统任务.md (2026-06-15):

# TFT + 旋转编码器 GUI 菜单系统

> 负责人：待分配 | 预计工期：1-2天 | 可配合 Claude Code/Codex 开发
> 硬件：ST7789 1.69" LCD (240×280) + EC11 旋转编码器 (已焊接)
> 管脚表：`kicad/模块管脚分配表.csv` 或 `CLAUDE.md` §Expansion Module

## 方案选择

### 为什么不推荐 LVGL

LVGL 需要 CPU (MicroBlaze/RISC-V) + 几十KB RAM + frame buffer (~135KB RGB565)，K325T 资源够但：
- MicroBlaze 软核引入工具链复杂度
- LVGL 移植和调试周期远超竞赛准备时间
- 240×280 分辨率下纯文字菜单已经够用

### 推荐：Tile-based 字符菜单系统

**核心思路**：将屏幕视为 30×17 字符网格 (8×16 字体)，FPGA 只存 510 字节字符码 + 2KB 字模 ROM，纯硬件渲染。

```
┌──────────────────────────────────────┐
│  AWG 任意波形信号发生器              │  ← 标题栏 (1行)
├──────────────────────────────────────┤
│                                     │
│   ▶ 频率:  50.000 000 MHz           │  ← 菜单项 (每项1行)
│     波形:  Sine                     │
│     幅度:  75%                      │
│     偏置:  0 mV                     │
│                                     │
│     扫频设置                        │
│     系统信息                        │
│                                     │
├──────────────────────────────────────┤
│  ↻旋转选择   ●按下确认              │  ← 状态栏 (1行)
└──────────────────────────────────────┘
```

## 系统架构

```
awg_top.v
  └── gui_top.v (新增顶层)
        ├── ec11_decoder.v     # 正交解码 + 消抖 + 按键检测
        ├── menu_controller.v  # 菜单状态机 + 字符帧缓存写入
        ├── char_rom.v         # 8×16 ASCII 字模 ROM (BRAM)
        ├── tile_renderer.v    # 字符码 → 像素数据 (实时扫描)
        └── st7789_driver.v    # SPI 时序 + 初始化序列
```

### 各模块说明

#### 1. ec11_decoder.v — 旋转编码器解码

```verilog
module ec11_decoder (
    input  clk,          // 建议用 clk_25m (SPI 时钟域)
    input  rst_n,
    input  ec11_a,       // A 相
    input  ec11_b,       // B 相
    input  ec11_btn,     // 按键 (带外部上拉)
    output reg signed [7:0] rotation,  // +1 或 -1 脉冲
    output reg btn_short,              // 短按 (单次脉冲)
    output reg btn_long                // 长按 (>1s)
);
```

**EC11 时序**：
```
顺时针 (CW):  A ──┐   ┌──┐   相位 A 领先 B 90°
              B ──┼──┐│┌─┼──  当 A↓ 且 B=1 → CW
逆时针 (CCW): A ──┐   ┌──┐   相位 B 领先 A 90°
              B ─┐┼──┘│└─┼─  当 A↓ 且 B=0 → CCW
```

**实现要点**：
- 用 25MHz 时钟过采样 A/B (机械编码器最高 ~10kHz)
- 2 级同步器消除亚稳态
- 状态机检测 A/B 边沿 → 输出 ±1 脉冲
- 按键消抖 ~20ms，长按判断 ~1s

#### 2. menu_controller.v — 菜单状态机

**菜单树结构**：

```
主菜单
├── 频率设置
│   ├── 粗调: 1MHz 步进
│   ├── 中调: 10kHz 步进
│   └── 细调: 1Hz 步进
├── 波形选择
│   ├── Sine / Square / Triangle / Saw / Arbitrary
├── 幅度设置
│   ├── 粗调 / 细调
├── 偏置设置
├── 扫频控制
│   ├── 起始频率 / 终止频率 / 步进 / 驻留时间
│   └── 启动 / 停止
├── 输出控制
│   └── 输出使能 ON/OFF
└── 系统信息
    ├── 设备 ID / 固件版本
    └── JESD 链路状态
```

**状态编码**：

```verilog
localparam MENU_MAIN       = 4'd0;
localparam MENU_FREQ       = 4'd1;
localparam MENU_WAVE       = 4'd2;
localparam MENU_AMP        = 4'd3;
localparam MENU_OFFSET     = 4'd4;
localparam MENU_SWEEP      = 4'd5;
localparam MENU_OUTPUT     = 4'd6;
localparam MENU_INFO       = 4'd7;

// 子状态
localparam SUB_SELECT      = 2'd0;  // 选择菜单项
localparam SUB_EDIT        = 2'd1;  // 编辑参数值
```

**与 awg_reg_bank 接口**：
- `menu_controller` 通过 UART 桥相同的寄存器接口写入 `awg_reg_bank`
- 频率/幅度/波形修改后触发 APPLY (写 0x2C)

#### 3. char_rom.v — 字模 ROM

```verilog
module char_rom (
    input  [7:0] char_code,   // ASCII 码 (0x20-0x7F)
    input  [3:0] row,          // 字符内行号 (0-15)
    output [7:0] bitmap        // 8 像素位图
);
```

- 覆盖 ASCII 32-127 (96 可打印字符)
- 每个字符 8×16 像素 → 96×16 = 1536 字节
- 使用 8×16 终端字体（如 Terminus, IBM VGA）
- BRAM 初始化用 `$readmemh`

**字体生成方法**：
```python
# Python 脚本：从 BDF/PCF 字体文件生成 .hex ROM 初始化文件
# 或直接硬编码 8×16 等宽字体
```

#### 4. tile_renderer.v — 字符渲染器

```verilog
module tile_renderer (
    input  clk,
    input  rst_n,
    // 连接到 ST7789
    output reg        tft_dc,    // 命令/数据
    output reg [7:0]  tft_data,  // SPI 数据
    output reg        tft_start  // 传输触发
);
```

- 每帧从 (0,0) 扫描到 (239,279)
- 每个像素：确定所在 tile (col, row) → 查字符码 → 查字模 → 输出颜色
- 行/场同步以匹配 ST7789 刷新率 (~60Hz)

**优化**：由于 ST7789 每次传输一个像素需要 ~20 SPI 时钟周期，30×17 字符 × 16 行 = 8160 次字模查找/帧。在 25MHz SPI 下，每像素约 0.8μs，全屏 ~53ms，可接受。

#### 5. st7789_driver.v — LCD 驱动

```verilog
module st7789_driver (
    input  clk,           // 25MHz (SPI 时钟)
    input  rst_n,
    // SPI 接口
    output reg  tft_scl,
    output reg  tft_sda,
    output reg  tft_cs,
    output reg  tft_dc,
    output reg  tft_res,
    output reg  tft_blk,
    // 像素输入
    input  [7:0] pixel_r,
    input  [7:0] pixel_g,
    input  [7:0] pixel_b,
    input        pixel_valid,
    output       pixel_ready
);
```

**初始化序列**（参考 ST7789 数据手册）：
```
复位 → SWRESET → SLPOUT → COLMOD(0x55=16bit) → MADCTL → 
INVON → NORON → DISPON
```

**像素写入流程**：
1. CASET (0x2A) — 设置列地址范围
2. RASET (0x2B) — 设置行地址范围
3. RAMWR (0x2C) — 连续写入像素数据

## 开发步骤 (1-2天)

### Day 1: EC11 编码器 (MVP)

| 步骤 | 任务 | 验证 |
|---|---|---|
| 1 | `ec11_decoder.v` — 正交解码 + 消抖 | LED 指示旋转方向 / ILA |
| 2 | EC11 → UART 命令桥 (CW=波形+, CCW=频率-, BTN=APPLY) | 示波器波形随旋钮变化 |
| 3 | 约束使能 (awg_k325t.xdc §14 取消注释) | 综合通过 |

**Day 1 即可交付**：旋钮控制 AWG 参数（脱离 PC）。

### Day 2: TFT 显示 (可选增强)

| 步骤 | 任务 | 验证 |
|---|---|---|
| 4 | `st7789_driver.v` — SPI 时序 + 初始化 + 纯色测试 | 屏亮 |
| 5 | `char_rom.v` + 单行文字显示 "AWG 50.0MHz Sine" | 屏显 |
| 6 | EC11 调参数时刷新显示 | 旋钮调→屏变 |

**备选极简方案**：EC11 直接发 UART 命令（字符终端），一天搞定。

## 与 Claude Code 协作提示

### 提示词模板

```
我需要为 FPGA 项目实现 ST7789 LCD 的 SPI 驱动。
请帮我写一个 Verilog 模块 st7789_driver.v：
- 25MHz SPI 时钟
- 3 线 SPI (SCL, SDA, CS) + DC (命令/数据切换) + RES + BLK
- 包含完整的初始化序列 (参考 ST7789V 数据手册)
- 支持连续写像素 (CASET + RASET + RAMWR)
- 像素输入接口: 8bit RGB + valid/ready 握手
```

```
帮我实现 EC11 旋转编码器的正交解码 Verilog 模块：
- 2 级同步器消抖
- 检测 CW/CCW 旋转 → 输出 ±1 脉冲
- 按键消抖 (20ms) + 长按检测 (1s)
```

### 参考资源

| 资源 | 用途 |
|---|---|
| ST7789V datasheet | 初始化序列、命令表、时序 |
| EC11 datasheet | 机械参数、电气特性 |
| `constraints/awg_k325t.xdc` §14 | 管脚约束（注释状态，取消注释即可用） |
| `rtl/jesd/spi_wr_rd_single.v` | 现有 SPI 控制器参考 |
| `rtl/control/awg_key_ui_ctrl.v` | 现有按键消抖逻辑参考 |

## 备选：极简 ASCII 终端方案

如果时间不够，可以用更简单的方式：EC11 只发 UART 命令，电脑上串口终端显示菜单。

```verilog
// EC11 转 UART 命令
// CW → 发送 "W 28 01\n" (切方波)
// CCW → 发送 "W 28 00\n" (切正弦)
// BTN → 发送 "W 2C 01\n" (APPLY)
```

此方案当天可完成，可用作 MVP 验证编码器硬件正常。

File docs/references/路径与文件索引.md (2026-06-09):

# 路径与文件索引

> 项目根：`D:\projects\GPR\Electronics-Competition`
> 最后更新：2026-06-09

---

## Vivado 工程

| 内容 | 路径 |
|---|---|
| 工程文件 | `vivado/awg_k325t.xpr` |
| 主顶层 | `rtl/top/awg_top.v` |
| 诊断顶层（ILA） | `rtl/top/awg_top_diag.v` |
| LED 测试顶层 | `rtl/top/awg_test_led.v` |
| 主约束 | `constraints/awg_k325t.xdc` |
| FMC 子卡约束 | `constraints/fmc_adda.xdc` |

## RTL 源码

### rtl/top/ — 顶层模块

| 文件 | 说明 |
|---|---|
| `awg_top.v` | 主顶层：DDS + JESD204B + UART + 按键控制 |
| `awg_top_diag.v` | 诊断顶层（含 ILA 探针） |
| `awg_test_led.v` | LED 测试环回顶层 |

### rtl/dds/ — DDS 信号发生

| 文件 | 说明 |
|---|---|
| `dds_compiler_wrapper.v` | Vivado DDS Compiler IP 封装 |
| `dds_nco.v` | 48bit NCO 频率合成 |
| `sine_lut.v` | 正弦查找表 |
| `wave_shape_gen.v` | 波形整形（正弦/三角/方波/锯齿波） |

### rtl/dsp/ — 信号处理

| 文件 | 说明 |
|---|---|
| `awg_core.v` | AWG 核心（DDS + 幅度/偏置 + 通道复用） |
| `amp_offset_scale.v` | 幅度/偏置缩放流水线 |
| `sample_mux.v` | 4 通道采样复用 |

### rtl/jesd/ — JESD204B 接口与 SPI 配置

| 文件 | 说明 |
|---|---|
| `ad9144_awg_cal.v` | AD9144 数字校准表 |
| `ad9144_awg_dds4.v` | AD9144 4 通道 DDS 数据拼接 |
| `ad9144_awg_reg_bank.v` | AD9144 寄存器组 |
| `ad9144_sample_packer.v` | AD9144 采样打包 |
| `ad9144_spi_wr_config.v` | AD9144 SPI 初始化序列 |
| `ad9144_uart_reg_bridge.v` | AD9144 UART 寄存器桥接 |
| `ad9250_spi_config.v` | AD9250 SPI 初始化序列 |
| `jesd_axi_read.v` | AXI4-Lite 读（JESD 状态） |
| `jesd_axi_write.v` | AXI4-Lite 写 |
| `jesd_data_parse.v` | JESD 数据解析（误码/同步检查） |
| `lmk_spi_wr_config.v` | LMK04828 SPI 初始化序列 |
| `rst_module.v` | 上电复位序列 |
| `spi_wr_rd_single.v` | SPI 单次读写控制器 |
| `uart_rx.v` | UART 接收（9600 8N1） |
| `uart_tx.v` | UART 发送 |

### rtl/control/ — 板载按键与 LED

| 文件 | 说明 |
|---|---|
| `awg_key_ui_ctrl.v` | 按键控制（频率/波形/幅度/偏置） |
| `awg_led_status.v` | LED 状态指示 |

### rtl/sweep/ — 扫频引擎

| 文件 | 说明 |
|---|---|
| `sweep_engine.v` | 可编程扫频发生器 |

### rtl/wave/ — BRAM 波形回放

| 文件 | 说明 |
|---|---|
| `bram_wave_player.v` | BRAM 预存波形回放 |

## 仿真

| 文件 | 说明 |
|---|---|
| `sim/tb/tb_awg_cal.v` | 校准表 testbench |
| `sim/tb/tb_awg_core.v` | AWG 核心 testbench |
| `sim/tb/tb_awg_key_ui_ctrl.v` | 按键控制 testbench |
| `sim/tb/tb_awg_led_status.v` | LED 状态 testbench |
| `sim/tb/tb_dds_compiler.v` | DDS Compiler testbench |
| `sim/tb/tb_key_led.v` | 按键 + LED 联合 testbench |
| `sim/run_simulation.tcl` | 仿真运行脚本（Vivado） |
| `sim/run_sim.ps1` | 仿真启动 PowerShell 脚本 |
| `sim/parse_vcd.py` | VCD 波形解析工具 |

## 脚本

| 文件 | 说明 |
|---|---|
| `scripts/build_all.tcl` | 完整工程构建 |
| `scripts/build_test_led.tcl` | LED 测试构建 |
| `scripts/fix_synth.tcl` | 官方推荐构建流程 |
| `scripts/verify_license.tcl` | License 验证 |
| `scripts/check_jesd204.tcl` | JESD204 IP 状态检查 |
| `scripts/probe_jesd204_params.tcl` | JESD204 参数探测 |
| `scripts/program.tcl` | Bitstream 下载 |
| `scripts/program_and_capture_awg_debug.tcl` | 下载并抓取调试数据 |
| `scripts/run_tb_key_led.tcl` | 按键 LED 仿真 |
| `scripts/run_vivado_bg.bat` | 后台启动 Vivado |
| `scripts/vivado_wrapper.ps1` | Vivado PowerShell 封装 |
| `scripts/launch_vivado.py` | Python 启动 Vivado |
| `scripts/kicad_grid_route_adapter.py` | KiCad 网格布线适配 |

## 文档

### docs/overview/ — 项目概述

| 文件 | 说明 |
|---|---|
| `项目简介.md` | 项目目标、进度、团队 |
| `硬件平台.md` | K7-325T + FMCADDA-9250-9144 硬件详述 |
| `软件工具链.md` | Vivado / 工具链配置 |

### docs/architecture/ — 系统架构

| 文件 | 说明 |
|---|---|
| `顶层架构图.md` | 系统顶层模块划分与数据流 |
| `时钟树.md` | 时钟分配与域分析 |

### docs/modules/ — 模块设计笔记

| 文件 | 说明 |
|---|---|
| `AD9144 Bring-Up.md` | AD9144 上电初始化流程 |
| `AD9144 UART Control.md` | UART 控制协议 |
| `JESD204数据链路.md` | JESD204B 链路建立与参数 |
| `LMK04828时钟配置.md` | LMK04828 SPI 配置 |
| `DDS波形生成.md` | DDS 频率合成原理与实现 |

### docs/timing/ — 时序约束

| 文件 | 说明 |
|---|---|
| `K325T约束速查.md` | 约束书写速查 |
| `时序与CDC风险.md` | 跨时钟域风险分析 |

### docs/troubleshooting/ — 问题排查

| 文件 | 说明 |
|---|---|
| `License与JESD204授权.md` | License 配置与 JESD204 IP 授权 |
| `Vivado常见错误.md` | 常见 Vivado 编译错误及对策 |
| `硬件验证流程.md` | 板级调试步骤 |

### docs/competition/ — 竞赛文档

| 文件 | 说明 |
|---|---|
| `design_document.md` | 竞赛设计报告 |
| `uni-trend-problem-statement.md` | 优利德赛题陈述 |
| `score_recovery_strategy.md` | 失分恢复策略 |
| `video_script.md` | 答辩视频脚本 |
| `竞赛答辩PPT.pptx` | 答辩演示文稿 |

### docs/references/ — 参考手册与原理图

| 文件 | 说明 |
|---|---|
| `FMCADDA-9250-9144子卡用户说明.pdf` | 子卡用户手册 |
| `FMC_9250_9144_BRD_SCH.pdf` | 子卡原理图 |
| `K7_BASE_1V3_2025_0111_USER.pdf` | 底板原理图 |
| `K7_IO.xdc` | 正点原子 K7 IO 约束参考 |
| `AD9144.pdf` | AD9144 四通道 DAC 数据手册 (🆕 2026-06-09) |
| `lmk04828.pdf` | LMK04828 时钟芯片数据手册 (🆕 2026-06-09) |
| `9250_9144_04828_125M_500M_gen.tcs` | TICS Pro 参考配置 (🆕 2026-06-09) |
| `kimi_agent_prompt.md` | Kimi Agent 任务提示词参考 |

### 根目录文档

| 文件 | 说明 |
|---|---|
| `README.md` | 项目总览、快速开始、仓库结构 |
| `fmc_adda_signal_map.md` | FMC 子卡↔底板完整管脚映射 |
| `ad9144_4x_interpolation_config.md` | AD9144 4×插值配置 |

## KiCad 硬件（扩展模块）

| 文件 | 说明 |
|---|---|
| `kicad/ProPrj_研电赛优利德显示屏与旋转编码器_2026-06-08.kicad_pcb` | PCB 设计 |
| `kicad/ProPrj_研电赛优利德显示屏与旋转编码器_2026-06-08.kicad_sch` | 原理图 |
| `kicad/design_lib.kicad_sym` | 自定义符号库 |
| `kicad/design_lib.pretty/` | 自定义封装库（C0603, R0603, SOT-23-3, EC11 等） |

## 杂项

| 文件 | 说明 |
|---|---|
| `sine.coe` | DDS Compiler COE 波形系数 |
| `ad9144_sine_4096.hex` | AD9144 校准表 HEX 数据 |

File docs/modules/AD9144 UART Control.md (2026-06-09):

# AD9144 UART Control

This note records the PC-control bring-up variant for the K325T AD9144 AWG path.

## Purpose

The user-confirmed button waveform demo remains the fallback baseline. The UART variant adds a PC-side register-control path so frequency, amplitude, phase, waveform, and output enable can be changed without recompiling FPGA logic.

## Key Files

```text
D:\FPGA\ad9144_bringup_k325t\docs\ad9144_uart_control_protocol.md
D:\FPGA\ad9144_bringup_k325t\docs\next_board_session_checklist.md
D:\FPGA\ad9144_bringup_k325t\rtl\awg\uart_rx.v
D:\FPGA\ad9144_bringup_k325t\rtl\awg\uart_tx.v
D:\FPGA\ad9144_bringup_k325t\rtl\awg\ad9144_uart_reg_bridge.v
D:\FPGA\ad9144_bringup_k325t\constraints\awg_uart_k325t.xdc
D:\FPGA\ad9144_bringup_k325t\tools\awg_uart_control.py
```

## Build And Program

Build:

```powershell
& D:\vivado\Vivado\2024.1\bin\vivado.bat -mode batch -tempDir C:/tmp/vivado_awg_uart_temp -journal C:/tmp/vivado_awg_uart.jou -log C:/tmp/vivado_awg_uart.log -source D:\FPGA\ad9144_bringup_k325t\scripts\build_awg_uart_direct.tcl
```

Program:

```powershell
& D:\vivado\Vivado\2024.1\bin\vivado.bat -mode batch -source D:\FPGA\ad9144_bringup_k325t\scripts\program_awg_uart.tcl
```

Generated bit:

```text
D:\FPGA\ad9144_bringup_k325t\vivado_awg_uart\top_awg_uart.bit
```

## UART Protocol

- 115200 baud, 8N1.
- Read: `R <addr_hex_2>`.
- Write: `W <addr_hex_2> <data_hex_8>`.
- Expected ID: `R 00` returns `D 41574731`.
- Enable register control: `W 08 00000003`.
- Return to button control: `W 08 00000001`.

## Host Smoke Test

After programming, wait 12-15 seconds for AD9144 startup.

```powershell
python D:\FPGA\ad9144_bringup_k325t\tools\awg_uart_control.py --port COM3 status
python D:\FPGA\ad9144_bringup_k325t\tools\awg_uart_control.py --port COM3 preset --frequency 50000000 --amplitude 0x6000 --wave sine
```

If the COM port is not `COM3`, list ports:

```powershell
Get-PnpDevice -PresentOnly -Class Ports
```

## Status

- UART bit generated on 2026-05-07.
- Bitstream write succeeded.
- Build log has a non-blocking `blk_mem_gen_0` locked-IP critical warning.
- Timing is not final-clean: route log reports setup violations around `WNS=-3.330ns`, `TNS=-3948.764ns`; hold is clean.
- Use this as a controlled bring-up artifact, then clean CDC/reset/debug timing before final competition measurements.

## 2026-05-07 Board Check

- Board was powered and JTAG was visible as `USB Serial Converter`, `VID_0403&PID_6014`, serial `210512180081`.
- `top_awg_uart.bit` was programmed successfully.
- Vivado reported `End of startup status: HIGH`.
- Vivado detected 3 ILA cores and 1 VIO core; missing probe-file warnings only affect debug signal names.
- No Windows `COM` port was present after programming. `Win32_SerialPort` and `[System.IO.Ports.SerialPort]::GetPortNames()` returned empty.
- Next action is physical: connect or enable a USB-UART adapter to the K325T UART pins (`uart_rxd=T23`, `uart_txd=T22`). After that, run `status` and expect `ID=0x41574731`.

## 2026-05-07 CH340 Validation

- CH340 enumerated as `USB-SERIAL CH340 (COM7)`.
- Board was power-cycled, so the fixed UART bit was reprogrammed over JTAG.
- First UART bridge build responded, but every other byte was skipped:
  - `D 41574731` appeared as `D4543`
  - `OK` appeared as `O`
- Root cause:
  - `ST_SEND` advanced before `uart_tx` had accepted the byte.
  - readback captured synchronous `cfg_rdata` one clock too early.
- Fix:
  - Added `ST_SEND_BUSY` and `ST_SEND_IDLE`.
  - Added `ST_RD_CAPTURE`.
  - Added static checks so this does not regress silently.
- Rebuilt and programmed `top_awg_uart.bit`; Vivado startup status was `HIGH`.
- Raw UART checks now pass:
  - `R 00` -> `D 41574731`
  - `R 04` -> `D 20260507`
  - `W 08 00000003` -> `OK`
  - `R 08` -> `D 00000003`
- Host tool checks pass:
  - `status` reports `ID=0x41574731`.
  - `preset --frequency 50000000 --amplitude 0x6000 --wave sine` enables register control.
  - Final readback: `CONTROL=0x00000003`, `PHASE_INC=0x0CCCCCCCCCCD`, `AMPLITUDE=0x6000`, `WAVE_MODE=0`.
- Current board state after this check: fixed UART bit is loaded, register control is enabled, and output is configured as 50 MHz sine at amplitude `0x6000`.
- User confirmed OUT1 shows a normal 50 MHz sine wave with this configuration.

## UART Panel

First GUI panel:

```text
D:\FPGA\ad9144_bringup_k325t\tools\awg_uart_panel.py
```

Launch:

```powershell
python D:\FPGA\ad9144_bringup_k325t\tools\awg_uart_panel.py
```

The panel can refresh COM ports, read status, apply a frequency/amplitude/phase/waveform preset, turn output off, and return to button control.

Validation:

```text
python -m py_compile ... -> pass
python awg_uart_panel.py --smoke -> AWG_UART_PANEL_IMPORT_OK
Port enumeration -> COM7
UART status -> ID=0x41574731
```

## Vivado Thread Setting

Shared scripts now set Vivado to 8 threads by default on this i7-11800H machine:

```text
D:\FPGA\scripts\vivado_threads.tcl
D:\FPGA\ad9144_bringup_k325t\scripts\vivado_threads.tcl
```

Override before running Vivado:

```powershell
$env:AWG_VIVADO_MAX_THREADS = "4"
```

Batch verification printed `AWG_VIVADO_MAX_THREADS=8`, `AWG_VIVADO_JOBS=8`, and `VIVADO_GENERAL_MAXTHREADS=8`.

## UART Sweep Logger

Tool:

```text
D:\FPGA\ad9144_bringup_k325t\tools\awg_uart_sweep.py
```

Dry run:

```powershell
python D:\FPGA\ad9144_bringup_k325t\tools\awg_uart_sweep.py --dry-run --out C:\tmp\awg_sweep_dry.csv
```

Live quick sweep:

```powershell
python D:\FPGA\ad9144_bringup_k325t\tools\awg_uart_sweep.py --port COM7 --profile quick --settle 0.05 --out D:\FPGA\ad9144_bringup_k325t\measurements\uart_sweeps\quick_latest.csv
```

Verified live quick sweep rows:

```text
10 MHz sine -> phase_inc 0x028F5C28F5C3
50 MHz sine -> phase_inc 0x0CCCCCCCCCCD
100 MHz sine -> phase_inc 0x19999999999A
```

The tool restores 50 MHz sine amplitude `0x6000` after live sweeps by default.

## GUI Sweep And Digital Wave Quality

The UART panel now has a `Run Sweep` button. It uses the same sweep engine as `awg_uart_sweep.py`, writes a CSV, restores 50 MHz sine at amplitude `0x6000`, and refreshes the register status.

Default GUI CSV:

```text
D:\FPGA\ad9144_bringup_k325t\measurements\uart_sweeps\gui_latest.csv
```

Digital self-check tool:

```text
D:\FPGA\ad9144_bringup_k325t\tools\awg_wave_quality.py
```

Quick run:

```powershell
python D:\FPGA\ad9144_bringup_k325t\tools\awg_wave_quality.py --profile quick --out D:\FPGA\ad9144_bringup_k325t\reports\wave_quality\quick_latest.csv
```

This models the RTL code path in `ad9144_awg_dds4.v`: 48-bit phase, four samples per beat, the 4096-point sine ROM, wave modes, Q15 amplitude, offset, and saturation. It is useful when no oscilloscope is nearby, but it is only a digital-code check and cannot prove AD9144 analog output quality.

Current quick digital baseline:

```text
10 MHz sine  -> THD -69.32 dBc, largest non-harmonic spur -77.89 dBc
50 MHz sine  -> THD -68.70 dBc, largest non-harmonic spur -75.48 dBc
100 MHz sine -> THD -66.84 dBc, largest non-harmonic spur -325.22 dBc
```

## Scope Measurement Workflow

Tool:

```text
D:\FPGA\ad9144_bringup_k325t\tools\awg_scope_measurement.py
```

Doc:

```text
D:\FPGA\ad9144_bringup_k325t\docs\awg_scope_measurement.md
```

Use it to create fillable measurement sheets from UART sweep CSVs and turn filled sheets into Markdown reports:

```powershell
python D:\FPGA\ad9144_bringup_k325t\tools\awg_scope_measurement.py template --from-sweep D:\FPGA\ad9144_bringup_k325t\measurements\uart_sweeps\scope_freq_response_rerun_20260507_1305.csv
python D:\FPGA\ad9144_bringup_k325t\tools\awg_scope_measurement.py report --input <filled_scope_csv> --out <scope_report_md>
```

2026-05-07 board note:

- OUT1 responded to UART-controlled frequency, amplitude, and waveform changes.
- Coarse sine sweep looked broadly normal through 300 MHz.
- 400 MHz looked like frequency jumping on the oscilloscope, but FPGA readback stayed stable at `PHASE_INC=0x666666666666`, `AMPLITUDE=0x6000`, `WAVE_MODE=0`, `CONTROL=0x00000003`.
- Treat the 400 MHz jump as oscilloscope counter/trigger/measurement behavior unless future instrument evidence says otherwise.

## Phase Handoff

Current handoff entry points:

```text
D:\FPGA\ad9144_bringup_k325t\README.md
D:\FPGA\ad9144_bringup_k325t\docs\phase_handoff_2026-05-07.md
```

These are the files to give another engineer first. They summarize the verified chain, build/program commands, GUI operation, measurement tools, generated-file policy, and recommended next tasks.

Current baseline to reproduce:

```text
ID=0x41574731
VERSION=0x20260507
CONTROL=0x00000003
PHASE_INC=0x0CCCCCCCCCCD
AMPLITUDE=0x6000
WAVE_MODE=0
```

Next work should focus on timing closure, proper measurement tables, THD/spur measurement, and amplitude calibration rather than re-proving basic UART/JESD/DAC connectivity.

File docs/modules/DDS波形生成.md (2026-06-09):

# DDS 波形生成

## 已完成内容

`D:\awg_fpga` 中的 DDS Compiler 验证路径已经跑通：

| 项目 | 状态 |
|---|---|
| DDS Compiler IP 配置 | 已完成 |
| Wrapper 封装 | 已完成 |
| 行为仿真 | 1 MHz / 2 MHz / 0 Hz 通过 |
| LED 板级测试 bitstream | 已生成 |

bit 文件：

```text
D:\awg_fpga\vivado\awg_k325t.runs\impl_1\awg_dds_led_top.bit
```

## DDS Compiler 参数

| 参数 | 值 |
|---|---|
| Phase Width | 48 bit |
| Output Width | 16 bit signed |
| Phase Increment | Programmable |
| Phase Out | disabled |

频率公式：

```text
f_out = phase_inc * f_clk / 2^48
phase_inc = f_out * 2^48 / f_clk
```

常用值：

| 目标频率  | 时钟 | Phase Inc |
| ----- | ---: | --- |
| 1 MHz | 100 MHz | `48'h28f5c28f5c2` |
| 2 MHz | 100 MHz | `48'h51eb851eb84` |
| 1 Hz  | 100 MHz | `48'h0000000002AF31` |
| 1 mHz | 100 MHz | `48'h0000000000000B` |

## 与 AD9144 路线的关系

DDS 本身不是当前阻塞。AD9144 standalone bring-up 目前使用 vendor ROM waveform，而不是最终 DDS 数据。正确顺序：

1. 用 vendor ROM 证明 JESD/AD9144 链路活着。
2. 用 ILA 看到 TX sample data 正在变化。
3. 再把 DDS/BRAM/DDR 数据接入 JESD transport。

## 关联文件

```text
D:\awg_fpga\rtl\dds\dds_compiler_wrapper.v
D:\awg_fpga\rtl\top\awg_dds_led_top.v
D:\awg_fpga\sim\tb\tb_dds_compiler.v
D:\awg_fpga\constraints\awg_dds_led_top.xdc
```

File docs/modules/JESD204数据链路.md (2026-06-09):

# JESD204 数据链路

## 当前状态

JESD204 vendor demo 已能完成综合、优化、布局、布线，但无法生成 bitstream。原因是缺少 Xilinx JESD204 LogiCORE 的 bitstream 授权，不是 K325T 器件 license、XDC 或 FMC 引脚错误。

错误原文见 [[License与JESD204授权]]。

## 链路目标

```mermaid
flowchart LR
    DATA["Vendor ROM / future AWG samples"] --> TX["JESD204 TX core"]
    TX --> PHY["JESD204 PHY / GTXE2"]
    PHY --> LANE["4 x C2M lanes"]
    LANE --> DAC["AD9144"]
    LMK["LMK04828 refclk/SYSREF"] --> PHY
    DAC --> SYNC["SYNC to FPGA"]
    SYNC --> TX
```

## 高速 lane 映射

| FMC signal | FPGA pins | Bank117 | 用途 |
| --- | --- | --- | --- |
| DP0_C2M_P/N | H2 / H1 | TX2 | DAC lane 0 |
| DP1_C2M_P/N | F2 / F1 | TX3 | DAC lane 1 |
| DP2_C2M_P/N | J4 / J3 | TX1 | DAC lane 2 |
| DP3_C2M_P/N | K2 / K1 | TX0 | DAC lane 3 |
| GBTCLK0_M2C_P/N | G8 / G7 | CLK0 | GTX refclk |

## 建链顺序

```text
1. LMK04828 SPI 配置
2. AD9144 SPI 配置
3. GTX refclk / QPLL lock
4. 释放 JESD204 TX reset
5. 等待 SYNC/SYSREF
6. TX tready 拉高
7. 发送 vendor ROM sample data
8. ILA 状态正常后再检查模拟输出
```

## ILA 最小检查项

| 信号 | 期望 |
|---|---|
| QPLL lock | 1 |
| TX reset done | 1 |
| TX tready | 1 |
| AD9144 SYNC status | 稳定 |
| SYSREF | 有活动 |
| TX sample data | 变化，不是全 0 |

## 不要做的事

- 不要在没有 bitstream 的情况下纠结示波器为什么没有波形。
- 不要把 `[Common 17-69]` 当成普通 K325T license 报错。
- 不要直接把 vendor `top.xdc` 用到 K325T，它不是本板的 FMC/GT 映射。

## 关联笔记

- [[AD9144 Bring-Up]]
- [[FMC引脚速查]]
- [[License与JESD204授权]]
- [[硬件验证流程]]

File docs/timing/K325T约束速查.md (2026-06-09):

# K325T 约束速查

## 原则

- 不要整文件包含 `K7_IO.xdc`。
- 只把当前顶层端口需要的引脚复制进工程约束。
- 每个顶层 IO 必须同时有 `PACKAGE_PIN` 和 `IOSTANDARD`。
- 差分时钟必须配合 RTL 中的 `IBUFDS` 使用。

## 查询入口

| 用途 | 文件 |
|---|---|
| 快速查 IO | `D:\FPGA\Kintex7\Kintex7\3_开发板原理图\K7_IO.xdc` |
| 表格查 IO | `D:\FPGA\Kintex7\Kintex7\3_开发板原理图\K7开发板IO引脚分配表.xlsx` |
| 电气确认 | `D:\FPGA\Kintex7\Kintex7\3_开发板原理图\K7_BASE_1V3_2025_0111_USER.pdf` |
| 核心板确认 | `D:\FPGA\Kintex7\Kintex7\3_开发板原理图\K7_CORE_V1.0.pdf` |

## 基础约束模板

```tcl
set_property PACKAGE_PIN AE10 [get_ports sys_clk_p]
set_property IOSTANDARD DIFF_SSTL15_DCI [get_ports sys_clk_p]
set_property PACKAGE_PIN AF10 [get_ports sys_clk_n]
set_property IOSTANDARD DIFF_SSTL15_DCI [get_ports sys_clk_n]
create_clock -period 10.000 -name sys_clk [get_ports sys_clk_p]

set_property PACKAGE_PIN AB25 [get_ports sys_rst_n]
set_property IOSTANDARD LVCMOS33 [get_ports sys_rst_n]

set_property PACKAGE_PIN R24 [get_ports {led[0]}]
set_property IOSTANDARD LVCMOS33 [get_ports {led[0]}]
set_property PACKAGE_PIN R23 [get_ports {led[1]}]
set_property IOSTANDARD LVCMOS33 [get_ports {led[1]}]
```

## 常见 DRC

| DRC | 含义 | 处理 |
|---|---|---|
| NSTD-1 | 端口没有 IOSTANDARD | 为所有顶层端口补 `IOSTANDARD` |
| UCIO-1 | 端口没有 PACKAGE_PIN | 为所有顶层端口补 `PACKAGE_PIN` |
| no_clock | 寄存器没有被约束时钟驱动 | 检查 create_clock/generated clock/CDC |

## AD9144 standalone XDC

当前 K325T-specific XDC：

```text
D:\FPGA\ad9144_bringup_k325t\constraints\top_k325t_fmc.xdc
```

不要使用 vendor demo 自带 `top.xdc`，它对应其他板卡/GT bank。

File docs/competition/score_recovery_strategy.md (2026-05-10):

# Fixed-Hardware Score Recovery Strategy

This strategy assumes the team will not buy additional high-end RF/DAC hardware. The goal is to maximize score from demonstrable engineering work on the existing K325T + FMCADDA-9250-9144 platform.

## Positioning

Do not claim the current hardware fully satisfies the highest analog-output targets. Present the project as a completed AWG prototype that proves the digital baseband, JESD204 DAC path, PC control, measurement workflow, and calibration strategy.

## High-Value Score Areas

| Area | Why It Scores | Concrete Deliverable |
|---|---|---|
| System completeness | Judges can operate a real end-to-end AWG, not just see isolated RTL | GUI + UART + FPGA + AD9144 OUT1 demo |
| Control precision | 48-bit DDS is a strong mathematical feature | Frequency-control formula, phase increment readback, low-frequency examples |
| Waveform diversity | Shows arbitrary-waveform direction even with a simple LUT engine | sine/square/triangle/saw demos and screenshots |
| Measurement rigor | Converts limited hardware into credible engineering evidence | `competition_measurement_report.md`, CSV templates, scope screenshots |
| Calibration | Shows awareness of analog non-idealities and a way to compensate them | before/after amplitude-response table |
| Automation | Reduces live-demo risk and improves repeatability | named demo presets, dry-run list, sweep scripts |
| Honest limitations | Avoids losing trust on impossible hardware claims | explicit hardware boundary slide |

## Recommended Demo Flow

1. Show hardware chain:

```text
PC GUI/CLI -> UART -> K325T register bank -> DDS4 -> JESD204 TX -> AD9144 -> OUT1 -> oscilloscope
```

2. Read status from the GUI and show `ID=0x41574731`.
3. Apply `baseline_50m`; show 50 MHz sine.
4. Apply `amp_low_50m` and `amp_high_50m`; show Vpp changes.
5. Apply `low_1m`, `mid_100m`, `high_300m`; show frequency control.
6. Apply square, triangle, and saw presets; show waveform switching.
7. Show the measurement report tables and calibration method.
8. Close with the hardware limitation and the upgrade path.

## What To Avoid

- Do not claim true 5 GSa/s analog output from the current OUT1 measurement.
- Do not claim 1 GHz analog bandwidth unless measured with credible termination, probe setup, and screenshots.
- Do not spend time designing new analog front-end hardware that cannot be built before the contest.
- Do not rely on only live oscilloscope operation; keep screenshots and CSV evidence ready.

## Next Engineering Tasks

| Priority | Task | Success Criterion |
|---:|---|---|
| 1 | Run the named demo presets on hardware | Each preset has a pass/fail row in the measurement report |
| 2 | Fill the frequency-response table | At least 1, 50, 100, and 300 MHz measured |
| 3 | Fill the amplitude-linearity table | `0x3000`, `0x6000`, `0x7000` measured at 50 MHz |
| 4 | Capture waveform screenshots | sine/square/triangle/saw screenshots saved |
| 5 | Run a simple calibration before/after | Vpp spread improvement documented |
| 6 | Prepare slides from evidence | Every claim points to a measurement or source file |

## Upgrade Path If Hardware Becomes Available

If funding appears later, the best upgrade is not a random analog board. The next hardware should specifically improve the bottleneck that limits contest score: a DAC path with documented >=5 GSa/s update rate, >=1 GHz usable analog output bandwidth, clean clocking, and a reference design compatible with the selected FPGA or a replacement FPGA board.

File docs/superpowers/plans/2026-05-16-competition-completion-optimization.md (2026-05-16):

# Competition Completion Optimization Implementation Plan

> **For agentic workers:** REQUIRED SUB-SKILL: Use superpowers:subagent-driven-development (recommended) or superpowers:executing-plans to implement this plan task-by-task. Steps use checkbox (`- [ ]`) syntax for tracking.

**Goal:** Turn the current K325T + AD9144 AWG prototype into the strongest contest-ready deliverable possible on the fixed hardware by improving code reliability, UI workflow, FPGA logic coverage, measurement evidence, and final presentation assets.

**Architecture:** Preserve the verified chain `PC Qt GUI/CLI -> CH340 UART -> K325T register bank -> DDS4/waveform/calibration logic -> JESD204 TX -> AD9144 OUT1`. Add a competition workflow layer above the existing control tools, add missing FPGA capabilities where they directly support the problem statement, and create a repeatable evidence package so every contest claim maps to code, readback, measurement, or an explicit hardware limitation.

**Tech Stack:** Vivado 2024.1 Enterprise, Verilog RTL, PowerShell/Tcl build scripts, Python 3, PySide6, pyqtgraph, pyserial, unittest, Markdown documentation.

---

## Current Review Snapshot

This plan was written against branch `codex/upper-host-smoke-checks` at commit `12aba67`, with PR #5 open against `main`.

Fresh no-hardware checks run during review:

```powershell
powershell -NoProfile -ExecutionPolicy Bypass -File ad9144_bringup_k325t\scripts\check_upper_host.ps1
powershell -NoProfile -ExecutionPolicy Bypass -File ad9144_bringup_k325t\scripts\check_awg_uart_control_wiring.ps1
powershell -NoProfile -ExecutionPolicy Bypass -File ad9144_bringup_k325t\scripts\check_awg_waveform_modes.ps1
powershell -NoProfile -ExecutionPolicy Bypass -File ad9144_bringup_k325t\scripts\check_awg_register_debug_wiring.ps1
powershell -NoProfile -ExecutionPolicy Bypass -File ad9144_bringup_k325t\scripts\check_awg_button_sequence.ps1
```

Observed review facts:

- `check_upper_host.ps1` prints `UPPER_HOST_CHECK_OK`; 4 backend tests pass.
- UART, waveform, register/debug, and button static wiring checks pass.
- `check_awg_waveform_modes.ps1` reports that the local generated button bitstream is absent, but static waveform-mode wiring passes.
- `ad9144_bringup_k325t/upper_host/main.py` is 1357 lines and mixes app shell, pages, widgets, settings, background task handling, and smoke logic.
- `ad9144_bringup_k325t/variants/awg_button/top.v` is 969 lines and remains the high-risk integration file.
- `sim/work/run_awg_core_sim.ps1`, `sim/work/run_awg_key_ui_ctrl_sim.ps1`, and `sim/work/run_awg_led_status_sim.ps1` still hardcode old `D:\awg_fpga` paths.
- The contest statement requires at least 5 GSa/s, 1 GHz bandwidth, 14-bit resolution, 1 mHz frequency resolution, sweep, amplitude range/flatness, THD, and non-harmonic spur evidence.
- The current fixed hardware path should not be claimed as full 5 GSa/s / 1 GHz analog compliance without credible measurement. The strongest honest position is a complete AWG prototype with verified digital control, JESD204 DAC output, guided GUI operation, calibration workflow, and documented hardware boundary.

---

## Optimization Matrix

| Area | Current Strength | Main Gap | Target Optimization |
|---|---|---|---|
| FPGA datapath | OUT1 responds to UART-controlled frequency, amplitude, and waveform changes | Fixed shape modes only; no true user waveform RAM; sweep mostly host/script driven | Add uploadable waveform RAM mode and a hardware sweep engine |
| Register/UART logic | ID/version/status/read-write path works | Register map needs growth without breaking old tools | Versioned register map, compatibility aliases, register-map tests |
| Timing/release confidence | Demo bit can be generated and observed | Timing history includes negative WNS in some builds | Add timing report parser, reset/CDC cleanup, release gate |
| Upper-host UI | PySide6 GUI exists with dashboard/control/measurement/calibration pages | No contest-focused guided flow; main window file is too large | Split UI into pages and add a guided competition workflow page |
| Measurements | CSV templates, digital QA, calibration generator exist | Filled analog evidence and before/after calibration proof are missing | Session-based measurement package with required evidence rows |
| Documentation | AGENTS/README/handoff docs are useful | Some docs are stale or absolute-path-heavy; claims need stronger evidence links | One source-of-truth contest evidence index and final claim table |
| Packaging | PyInstaller script exists | No release manifest tying EXE, bitstream, commit, and measurements together | Build a release package manifest and checklist |

---

## File Structure

### New Files

- `scripts/check_project_health.ps1`: top-level no-hardware health gate that calls upper-host checks and FPGA static checks.
- `ad9144_bringup_k325t/upper_host/app.py`: thin application bootstrap and `QApplication` setup.
- `ad9144_bringup_k325t/upper_host/widgets.py`: reusable cards, state pills, preview tables, and plotting widgets.
- `ad9144_bringup_k325t/upper_host/pages/dashboard.py`: dashboard page.
- `ad9144_bringup_k325t/upper_host/pages/control.py`: manual control and demo preset page.
- `ad9144_bringup_k325t/upper_host/pages/measurements.py`: scope template/report/wave-quality page.
- `ad9144_bringup_k325t/upper_host/pages/calibration.py`: calibration table editor/dump/load page.
- `ad9144_bringup_k325t/upper_host/pages/competition.py`: guided contest demo workflow page.
- `ad9144_bringup_k325t/upper_host/demo_session.py`: typed model for demo steps, expected observations, and evidence status.
- `ad9144_bringup_k325t/upper_host/evidence.py`: evidence artifact index, screenshot/CSV registration, and claim table export.
- `ad9144_bringup_k325t/tools/awg_waveform_file.py`: parse CSV/TXT/COE waveform files into signed 16-bit samples.
- `ad9144_bringup_k325t/rtl/awg/ad9144_wave_ram.v`: uploadable 4096-entry waveform RAM.
- `ad9144_bringup_k325t/rtl/awg/ad9144_sweep_engine.v`: register-controlled linear/log-style phase-increment sweep controller.
- `ad9144_bringup_k325t/rtl/awg/tb_ad9144_wave_ram.v`: waveform RAM simulation.
- `ad9144_bringup_k325t/rtl/awg/tb_ad9144_sweep_engine.v`: sweep engine simulation.
- `ad9144_bringup_k325t/scripts/check_timing_report.ps1`: parse Vivado timing summaries and fail release gates on negative WNS unless explicitly allowed.
- `ad9144_bringup_k325t/scripts/build_release_package.ps1`: create a local release package with manifest, source commit, EXE path, bitstream path, and evidence files.
- `docs/competition/evidence_index.md`: contest claim-to-evidence table.
- `docs/competition/final_validation_checklist.md`: board, scope, GUI, and documentation validation sequence.

### Modified Files

- `ad9144_bringup_k325t/upper_host/main.py`: reduce to a compatibility wrapper that imports `app.main`.
- `ad9144_bringup_k325t/upper_host/backend.py`: keep hardware and file operations, move UI-free session/evidence logic to new modules.
- `ad9144_bringup_k325t/tools/awg_uart_control.py`: add waveform upload and sweep-control subcommands.
- `ad9144_bringup_k325t/tools/awg_scope_measurement.py`: add evidence session identifiers and required contest fields.
- `ad9144_bringup_k325t/rtl/awg/ad9144_awg_dds4.v`: add uploaded-waveform mode and sweep phase input.
- `ad9144_bringup_k325t/rtl/awg/ad9144_awg_reg_bank.v`: add waveform upload, sweep, evidence-friendly status, and register-map version fields.
- `ad9144_bringup_k325t/rtl/awg/ad9144_uart_reg_bridge.v`: route new register writes and support waveform table writes.
- `ad9144_bringup_k325t/variants/awg_button/top.v`: instantiate waveform RAM and sweep engine while preserving the existing button fallback.
- `ad9144_bringup_k325t/docs/ad9144_uart_control_protocol.md`: update the register map and examples.
- `ad9144_bringup_k325t/docs/awg_register_map.md`: update register map with compatibility notes.
- `ad9144_bringup_k325t/README.md`, `ad9144_bringup_k325t/AGENTS.md`, `README.md`: link the health gate, competition workflow, and release checklist.
- `docs/competition/design_document.md`: align protocol, UI, measurement, and limitations with current implementation.
- `docs/competition/video_script.md`: update the final demonstration sequence.
- `sim/work/run_awg_core_sim.ps1`, `sim/work/run_awg_key_ui_ctrl_sim.ps1`, `sim/work/run_awg_led_status_sim.ps1`: remove old absolute paths.

---

## Phase 0: Baseline And Mainline Hygiene

### Task 0.1: Merge The Existing Upper-Host Smoke PR

**Files:**
- No source file changes.

- [ ] **Step 1: Confirm PR #5 is clean**

Run:

```powershell
gh pr view 5 --json state,mergeStateStatus,mergeable,statusCheckRollup,headRefName,baseRefName
```

Expected:

```text
"state": "OPEN"
"mergeStateStatus": "CLEAN"
"mergeable": "MERGEABLE"
"headRefName": "codex/upper-host-smoke-checks"
"baseRefName": "main"
```

- [ ] **Step 2: Re-run the PR health check**

Run:

```powershell
powershell -NoProfile -ExecutionPolicy Bypass -File ad9144_bringup_k325t\scripts\check_upper_host.ps1
```

Expected:

```text
UPPER_HOST_CHECK_OK
Ran 4 tests
OK
```

- [ ] **Step 3: Merge PR #5**

Run:

```powershell
gh pr merge 5 --merge
git fetch origin --prune
git log --oneline --decorate -3 origin/main
```

Expected: `origin/main` contains a merge commit for PR #5.

- [ ] **Step 4: Create a new optimization branch**

Run:

```powershell
git checkout -b codex/competition-completion-optimization origin/main
```

Expected: branch switches to `codex/competition-completion-optimization` with a clean worktree.

### Task 0.2: Add A Top-Level Project Health Gate

**Files:**
- Create: `scripts/check_project_health.ps1`
- Modify: `README.md`
- Modify: `AGENTS.md`

- [ ] **Step 1: Create the top-level health script**

Create `scripts/check_project_health.ps1` with this behavior:

```powershell
[CmdletBinding()]
param(
    [string]$Python = "python",
    [switch]$SkipQtSmoke,
    [switch]$SkipStaticRtl
)

$ErrorActionPreference = "Stop"
Set-StrictMode -Version Latest

$ScriptDir = Split-Path -Parent $MyInvocation.MyCommand.Path
$RepoRoot = Resolve-Path (Join-Path $ScriptDir "..")

Push-Location $RepoRoot
try {
    Write-Host "[health] Upper host"
    $upperArgs = @("-NoProfile", "-ExecutionPolicy", "Bypass", "-File", "ad9144_bringup_k325t\scripts\check_upper_host.ps1", "-Python", $Python)
    if ($SkipQtSmoke) {
        $upperArgs += "-SkipQtSmoke"
    }
    & powershell @upperArgs
    if ($LASTEXITCODE -ne 0) {
        throw "upper-host health check failed"
    }

    if (-not $SkipStaticRtl) {
        Write-Host "[health] AD9144 static RTL wiring"
        $checks = @(
            "check_awg_button_sequence.ps1",
            "check_awg_waveform_modes.ps1",
            "check_awg_register_debug_wiring.ps1",
            "check_awg_uart_control_wiring.ps1"
        )
        foreach ($check in $checks) {
            & powershell -NoProfile -ExecutionPolicy Bypass -File (Join-Path "ad9144_bringup_k325t\scripts" $check)
            if ($LASTEXITCODE -ne 0) {
                throw "$check failed"
            }
        }
    }

    git diff --check
    if ($LASTEXITCODE -ne 0) {
        throw "git diff --check failed"
    }

    Write-Host "PROJECT_HEALTH_OK"
}
finally {
    Pop-Location
}
```

- [ ] **Step 2: Run the health script**

Run:

```powershell
powershell -NoProfile -ExecutionPolicy Bypass -File scripts\check_project_health.ps1
```

Expected:

```text
PROJECT_HEALTH_OK
```

- [ ] **Step 3: Document the health gate**

Add this command to `README.md` and `AGENTS.md`:

```powershell
powershell -NoProfile -ExecutionPolicy Bypass -File scripts\check_project_health.ps1
```

- [ ] **Step 4: Commit**

Run:

```powershell
git add scripts/check_project_health.ps1 README.md AGENTS.md
git commit -m "test: add project health gate"
```

---

## Phase 1: Code Structure And Maintainability

### Task 1.1: Split The Qt Upper Host Into Focused Modules

**Files:**
- Create: `ad9144_bringup_k325t/upper_host/app.py`
- Create: `ad9144_bringup_k325t/upper_host/widgets.py`
- Create: `ad9144_bringup_k325t/upper_host/pages/__init__.py`
- Create: `ad9144_bringup_k325t/upper_host/pages/dashboard.py`
- Create: `ad9144_bringup_k325t/upper_host/pages/control.py`
- Create: `ad9144_bringup_k325t/upper_host/pages/measurements.py`
- Create: `ad9144_bringup_k325t/upper_host/pages/calibration.py`
- Modify: `ad9144_bringup_k325t/upper_host/main.py`
- Modify: `ad9144_bringup_k325t/launch_upper_host.py`
- Test: `ad9144_bringup_k325t/tests/test_upper_host_backend.py`

- [ ] **Step 1: Move reusable widgets**

Move these classes from `upper_host/main.py` to `upper_host/widgets.py` without behavior changes:

```python
class MetricCard(QFrame): ...
class StatePill(QLabel): ...
class PlotCard(QFrame): ...
class ListPreviewTable(QTableWidget): ...
```

Keep their public methods unchanged:

```python
MetricCard.set_value(value: str) -> None
MetricCard.set_subtitle(value: str) -> None
StatePill.set_state(text: str, *, on: bool = False, warn: bool = False, bad: bool = False) -> None
PlotCard.set_curve(x, y, *, title: str = "", subtitle: str = "") -> None
ListPreviewTable.load_csv(path: Path, limit: int = 200) -> None
```

- [ ] **Step 2: Move page classes**

Move each page class to its own file:

```text
DashboardPage -> pages/dashboard.py
ControlPage -> pages/control.py
MeasurementPage -> pages/measurements.py
CalibrationPage -> pages/calibration.py
```

Keep constructor signature `__init__(self, main: UpperHostWindow)` for each page.

- [ ] **Step 3: Move app shell**

Move `UpperHostWindow`, `ControlSettings`, `SignalHub`, `_std_icon`, `_open_path`, `_parse_optional_float`, `_read_csv_rows`, and `_write_csv_rows` to `upper_host/app.py`.

Make `upper_host/main.py` a compatibility wrapper:

```python
from __future__ import annotations

from .app import main

if __name__ == "__main__":
    raise SystemExit(main())
```

- [ ] **Step 4: Run the upper-host check**

Run:

```powershell
powershell -NoProfile -ExecutionPolicy Bypass -File ad9144_bringup_k325t\scripts\check_upper_host.ps1
```

Expected: `UPPER_HOST_CHECK_OK`.

- [ ] **Step 5: Commit**

Run:

```powershell
git add ad9144_bringup_k325t/upper_host ad9144_bringup_k325t/launch_upper_host.py
git commit -m "refactor: split upper host pages"
```

### Task 1.2: Remove Old Absolute Paths From Simulation Scripts

**Files:**
- Modify: `sim/work/run_awg_core_sim.ps1`
- Modify: `sim/work/run_awg_key_ui_ctrl_sim.ps1`
- Modify: `sim/work/run_awg_led_status_sim.ps1`

- [ ] **Step 1: Replace fixed root paths**

In each script, replace hardcoded assignments like:

```powershell
$vivado_bin = "D:\vivado\Vivado\2024.1\bin"
$rtl_dds = "D:\awg_fpga\rtl\dds"
$work_dir = "D:\awg_fpga\sim\work"
```

with root-derived paths:

```powershell
$ScriptDir = Split-Path -Parent $MyInvocation.MyCommand.Path
$RepoRoot = Resolve-Path (Join-Path $ScriptDir "..\..")
$vivado_bat = $env:VIVADO_PATH
if ([string]::IsNullOrWhiteSpace($vivado_bat)) {
    $vivado_bat = "D:\vivado\Vivado\2024.1\bin\vivado.bat"
}
$rtl_dds = Join-Path $RepoRoot "rtl\dds"
$rtl_dsp = Join-Path $RepoRoot "rtl\dsp"
$tb_dir = Join-Path $RepoRoot "sim\tb"
$work_dir = Join-Path $RepoRoot "sim\work\<script-specific-subdir>"
```

- [ ] **Step 2: Run the scripts if Vivado is available**

Run:

```powershell
powershell -NoProfile -ExecutionPolicy Bypass -File sim\work\run_awg_key_ui_ctrl_sim.ps1
powershell -NoProfile -ExecutionPolicy Bypass -File sim\work\run_awg_led_status_sim.ps1
powershell -NoProfile -ExecutionPolicy Bypass -File sim\work\run_awg_core_sim.ps1
```

Expected: each script reports its testbench pass marker or exits with code 0.

- [ ] **Step 3: Add no-Vivado fallback documentation**

If Vivado is not available, document the skipped command and keep this verification command passing:

```powershell
powershell -NoProfile -ExecutionPolicy Bypass -File scripts\check_project_health.ps1 -SkipStaticRtl
```

- [ ] **Step 4: Commit**

Run:

```powershell
git add sim/work/run_awg_core_sim.ps1 sim/work/run_awg_key_ui_ctrl_sim.ps1 sim/work/run_awg_led_status_sim.ps1
git commit -m "fix: make simulation scripts path portable"
```

---

## Phase 2: Contest-Focused UI Workflow

### Task 2.1: Add A Guided Competition Demo Page

**Files:**
- Create: `ad9144_bringup_k325t/upper_host/demo_session.py`
- Create: `ad9144_bringup_k325t/upper_host/pages/competition.py`
- Modify: `ad9144_bringup_k325t/upper_host/app.py`
- Test: `ad9144_bringup_k325t/tests/test_upper_host_backend.py`

- [ ] **Step 1: Add the demo step model**

Create `demo_session.py` with immutable step definitions:

```python
from __future__ import annotations

from dataclasses import dataclass

@dataclass(frozen=True, slots=True)
class DemoStep:
    key: str
    title: str
    preset: str
    expected_scope: str
    evidence_kind: str
    claim: str

DEMO_STEPS = [
    DemoStep("status", "Read board status", "baseline_50m", "ID=0x41574731 in GUI", "status", "PC-to-FPGA control path is alive"),
    DemoStep("baseline", "50 MHz sine baseline", "baseline_50m", "Stable 50 MHz sine on OUT1", "scope", "Known-good sine output"),
    DemoStep("amplitude_low", "Amplitude low point", "amp_low_50m", "Vpp lower than baseline", "scope", "Amplitude control works"),
    DemoStep("amplitude_high", "Amplitude high point", "amp_high_50m", "Vpp higher than baseline without severe clipping", "scope", "Amplitude range is controllable"),
    DemoStep("low_freq", "1 MHz sine point", "low_1m", "Frequency near 1 MHz", "scope", "Frequency control spans low range"),
    DemoStep("mid_freq", "100 MHz sine point", "mid_100m", "Frequency near 100 MHz", "scope", "Mid-band output is reachable"),
    DemoStep("high_freq", "300 MHz sine point", "high_300m", "Frequency near 300 MHz, distortion noted honestly", "scope", "High-frequency operation is demonstrated"),
    DemoStep("square", "Square waveform", "square_50m", "Square-like output visible", "scope", "Waveform mode switches"),
    DemoStep("triangle", "Triangle waveform", "triangle_50m", "Triangle-like output visible", "scope", "Waveform mode switches"),
    DemoStep("saw", "Sawtooth waveform", "saw_50m", "Sawtooth-like output visible", "scope", "Waveform mode switches"),
]

def step_keys() -> list[str]:
    return [step.key for step in DEMO_STEPS]
```

- [ ] **Step 2: Add tests for step/preset consistency**

Add this test to `test_upper_host_backend.py`:

```python
def test_competition_demo_steps_reference_valid_presets(self) -> None:
    from ad9144_bringup_k325t.upper_host.demo_session import DEMO_STEPS

    preset_names = set(backend.demo_preset_names())
    self.assertGreaterEqual(len(DEMO_STEPS), 8)
    for step in DEMO_STEPS:
        self.assertIn(step.preset, preset_names)
        self.assertTrue(step.expected_scope)
        self.assertTrue(step.claim)
```

- [ ] **Step 3: Create the page**

Create `pages/competition.py` with a `CompetitionPage(QWidget)` containing:

```text
left column: ordered demo steps
center: selected step details and expected scope observation
right: evidence status fields for screenshot path, CSV row status, pass/fail note
bottom buttons: Apply Preset, Mark Observed, Mark Needs Repeat, Open Evidence Folder
```

Use existing `UpperHostWindow.apply_selected_demo()` logic by setting the Control page demo combo before applying.

- [ ] **Step 4: Add the page to navigation**

In `app.py`, add `CompetitionPage` to the stacked pages after Dashboard and before Control. Label it `Competition`.

- [ ] **Step 5: Verify UI smoke**

Run:

```powershell
powershell -NoProfile -ExecutionPolicy Bypass -File ad9144_bringup_k325t\scripts\check_upper_host.ps1
```

Expected: `UPPER_HOST_CHECK_OK`.

- [ ] **Step 6: Commit**

Run:

```powershell
git add ad9144_bringup_k325t/upper_host ad9144_bringup_k325t/tests/test_upper_host_backend.py
git commit -m "feat: add guided competition demo page"
```
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

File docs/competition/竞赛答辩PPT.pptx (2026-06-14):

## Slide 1

基于JESD204B的高速
任意波形信号发生器设计

第二十一届中国研究生电子设计竞赛 · 优利德命题

参赛队伍：[队伍名称]
所属高校：[学校名称]
团队成员：[队员1] / [队员2] / [队员3]
指导教师：[指导教师姓名]

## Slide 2

汇报提纲

15分钟汇报 + 5分钟问答

01 项目背景与赛题解读
02 技术指标对标分析
03 系统总体架构
04 核心技术：JESD204B / DDS / 时钟系统
05 控制与交互方案
06 扫频与任意波形功能
07 PCB丝印合规说明
08 关键技术难点与解决方案
09 测试验证与创新点总结
10 总结与展望

研电赛 · 优利德命题 · 任意波形信号发生器

2

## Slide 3

项目背景与赛题解读

应用背景

任意波形发生器 (AWG) 是电子测试测量领域的核心仪器
广泛应用于通信系统测试、雷达信号仿真、IC测试等场景
高速高精度AWG长期被Keysight、Tektronix等国外厂商垄断
国产化替代需求迫切，优利德命题服务于国产替代战略

研电赛 · 优利德命题 · 任意波形信号发生器

核心赛题指标

采样率 | ≥ 5 GSa/s
模拟带宽 | ≥ 1 GHz
垂直分辨率 | ≥ 14 bit
频率范围 | 1 mHz ~ 1 GHz
频率分辨率 | ≤ 1 mHz
谐波/杂散 | ≤ -40 dBc / -60 dBc
输出幅度 | 10 mVpp ~ 3 Vpp (50Ω)
带内平坦度 | < 3 dB

3

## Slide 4

技术指标对标分析

指标项 | 赛题要求 | 本方案实现 | 状态
采样率 | ≥ 5 GSa/s | 2.8 GSa/s (AD9144) | ⚠️ 部分达标
垂直分辨率 | ≥ 14 bit | 16 bit | ✅ 超标
通道数 | ≥ 2 | 4 通道独立输出 | ✅ 超标
频率分辨率 | ≤ 1 mHz | ~3.55 μHz (48bit DDS) | ✅ 远超
正弦最小频率 | ≤ 1 mHz | 48bit相位累加器，理论<1μHz | ✅ 达标
最高频率 | ≥ 1 GHz | [预计 ~800 MHz @2.8G] | ⚠️ 待实测
波形类型 | 支持任意波形 | 正弦/方波/三角/锯齿 + BRAM回放 | ✅ 达标
扫频功能 | 线性/对数 | 线性扫频引擎 + UART扫频脚本 | ✅ 达标
PCB 丝印 | 研电赛Logo+日期 | KiCad 扩展模块 PCB | ✅ 达标

✅ = 达标/超标 ⚠️ = 部分达标需说明

研电赛 · 优利德命题 · 任意波形信号发生器

4

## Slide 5

系统总体架构

FPGA 数字基带 + JESD204B 高速链路 + AD9144 DAC

按键 UI
KEY0/KEY1

初始化状态机
7态顺序执行

数字校准
awg_cal (BRAM)

Sample Packer
4×16b → 128b

GTXE2 PHY
QPLL + 4 GTX

UART
115200 8N1

寄存器控制层
awg_reg_bank

4路并行 DDS
48bit + Sine LUT

JESD204B TX Core
4L @10Gbps

FMC HPC 连接器

AD9144 DAC
4ch 16bit 2.8G

扩展模块
ST7789+EC11
(Logo丝印)

LMK04828
时钟芯片

FPGA 数字基带 (XC7K325T) → JESD204B 4L @10Gbps → FMC HPC → AD9144 DAC → 4路模拟输出

研电赛 · 优利德命题 · 任意波形信号发生器

5

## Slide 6

核心技术 1：高速 JESD204B 接口

4 Lanes × 10.3125 Gbps, Subclass 1 确定性延迟

协议层配置

L=4, M=4, F=4, S=1, K=32
线速率：10.3125 Gbps / lane
编码：8B/10B (25% 开销)
有效带宽：~33 Gbps
时钟：QPLL @5.15625 GHz
确定性延迟：Subclass 1 SYSREF

研电赛 · 优利德命题 · 任意波形信号发生器

链路建立流程

① 时钟配置：LMK04828 输出 DEVCLK + SYSREF
② QPLL 锁定：GTX 参考时钟 125MHz → QPLL 5.15625GHz
③ CGS 阶段：K28.5 码组同步
④ ILAS 阶段：通道对齐 + 链路参数校验
⑤ DATA 阶段：用户数据传输 (DDS 波形数据)

6
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

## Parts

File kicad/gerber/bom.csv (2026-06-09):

Refs | Value | Footprint | Qty | DNP
C1 | 100nF | design_lib:C0603 | 1
C2 | 100nF | design_lib:C0603 | 1
C3 | 100nF | design_lib:C0603 | 1
C4 | 0.1uF | design_lib:C0603 | 1
C5 | 0.1uF | design_lib:C0603 | 1
C6 | 0.1uF | design_lib:C0603 | 1
H3 | PZ254V-12-18P | design_lib:HDR-TH_18P-P2.54-V-M-R2-C9-S2.54 | 1
Q1 | S8050 | design_lib:SOT-23-3_L2.9-W1.3-P1.90-LS2.4-BR | 1
R1 | 10kΩ | design_lib:R0603 | 1
R2 | 10R | design_lib:R0603 | 1
R3 | 1kΩ | design_lib:R0603 | 1
R4 | 4.7K | design_lib:R0603 | 1
R5 | 4.7K | design_lib:R0603 | 1
R6 | 4.7K | design_lib:R0603 | 1
SW1 | EC11N1525405 | design_lib:EC11_ROTARY_ENCODER | 1
U1 | ST7789_12P_LCD | design_lib:ST7789_12P_1x12_1.00mm | 1

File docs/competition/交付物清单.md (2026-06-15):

# 研电赛交付物清单

> 优利德命题 · 赛题二 · 任意波形信号发生器
> 最后更新：2026-06-15

---

## 一、技术类竞赛基础材料（必须）

| # | 材料 | 要求 | 状态 | 文件 |
|---|---|---|:----:|---|
| 1 | **技术论文** | 学术论文格式，含摘要、方案、关键技术、测试结果、结论 | ✅ | `docs/competition/技术论文.md` |
| 2 | **演示视频** | 方案介绍 + 功能演示，建议 10-15 分钟 | ❌ | `docs/competition/video_script.md` (脚本已备) |
| 3 | **作品照片** | 实物照片（开发板 + 子卡 + 扩展模块 + 示波器波形截图） | ❌ | 待拍摄 |
| 4 | **电路图/PCB** | 核心电路设计文件 | ✅ | `kicad/` (扩展模块) |

## 二、企业命题追加材料（优利德要求）

| # | 材料 | 要求 | 状态 | 文件 |
|---|---|---|:----:|---|
| 1 | **系统方案介绍 PPT** | 方案介绍、技术亮点、创新点 | ✅ | `docs/competition/竞赛答辩PPT.pptx` |
| 2 | **方案设计与实现文档** | 详细技术文档 | ✅ | `docs/competition/design_document.md` |
| 3 | **功能演示视频** | 波形输出演示 + 控制操作 | ❌ | 同基础材料 #2 |
| 4 | **带注释工程源代码** | 可编译演示 | ✅ | `rtl/` + `scripts/` |

## 三、已完成的支持材料

| 材料 | 文件 |
|---|---|
| 赛题原文 (官方PDF) | `docs/references/研电赛第21届技术竞赛赛题清单.pdf` |
| 赛题原文 (文本) | `docs/competition/uni-trend-problem-statement.md` |
| 测试方案 | `docs/competition/AWG指标测试方案.md` |
| 测试记录（部分） | `docs/competition/AWG指标测试结果记录.md` |
| PPT 内容大纲 | `docs/competition/答辩PPT内容大纲.md` |
| 演示视频脚本 | `docs/competition/video_script.md` |
| 工程速查手册 | `CLAUDE.md` |
| 项目首页 | `README.md` |
| 扩展模块管脚 | `kicad/模块管脚分配表.csv` |
| SFCW/FMCW 开发任务 | `docs/tasks/SFCW_FMCW_波形生成任务.md` |
| TFT+EC11 GUI 开发任务 | `docs/tasks/TFT_Encoder_GUI_菜单系统任务.md` |

## 四、待完成

| 优先级 | 事项 | 预计耗时 |
|:---:|---|:---:|
| 🔴 高 | 录制演示视频 | 半天 |
| 🔴 高 | 拍摄作品照片 + 示波器波形截图 | 1 小时 |
| 🟡 中 | 频谱仪频域测试 (THD/SFDR/ENOB) | 半天 |
| 🟡 中 | 扩展模块 FPGA 驱动 (EC11 + ST7789) | 1-2天 |
| 🟢 低 | 对数扫频 | 1天 |
| 🟢 低 | 数字校准表实例化 | 1天 |

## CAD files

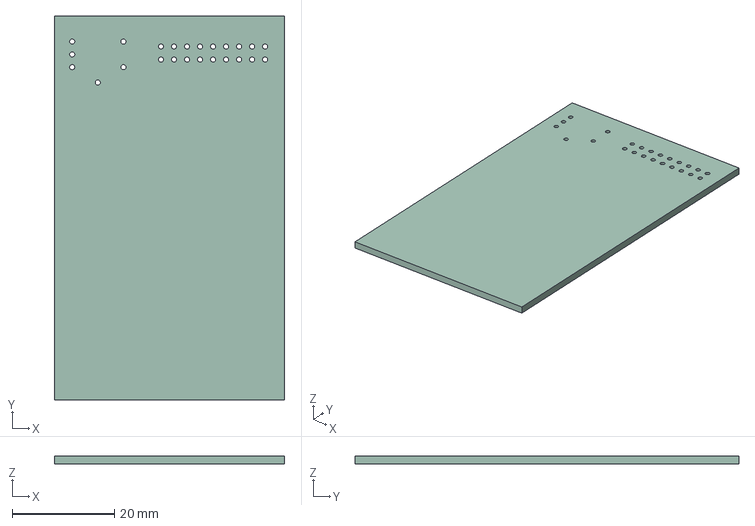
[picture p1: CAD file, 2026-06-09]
kicad/gerber/ProPrj_研电赛优利德显示屏与旋转编码器_2026-06-08.step
45.0 x 75.0 x 1.51 mm

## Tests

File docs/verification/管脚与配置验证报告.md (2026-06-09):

# 管脚与配置验证报告

**日期：** 2026-06-09

**工程：** AWG K325T FPGA — 任意波形发生器（DAC only, ADC 已剥离）

**构建状态：** ✅ Synth + Impl + Bitstream PASS (0 Errors, 14 Warnings, 0 Critical Warnings)

---

## 1. 管脚映射验证

### 1.1 LMK04828 SPI 信号（关键修复）

| 信号 | 子卡焊盘 | FMC 引脚 | LA 信号 | FPGA 管脚 | 原 awg_k325t.xdc 错误值 | 修复后 | 结果 |
|---|---|---|---|---|---|---|:----:|
| `lmk04828_spi_sclk` | G31 | J34B G31 | **LA29_N** | **E16** | AD29 (FMC I2C_SCL) | E16 | ✅ 已修复 |
| `lmk04828_spi_sdio` | H32 | J34B H32 | **LA28_N** | **J12** | AE29 (FMC I2C_SDA) | J12 | ✅ 已修复 |
| `lmk04828_cs_n` | H31 | J34B H31 | LA28_P | J11 | J11 | J11 | ✅ 正确 |
| `lmk04828_reset` | G30 | J34B G30 | LA29_P | F15 | F15 | F15 | ✅ 正确 |

**验证来源：**
- 子卡用户说明 PDF 第 8 页《FMC HPC 接口信号列表》明确列出：
  - `FMC_ADK_SCLK → G31 → LA29_N`
  - `FMC_ADK_SDIO → H32 → LA28_N`
- 底板原理图 `K7_BASE_1V3_2025_0111_USER.pdf` 确认 LA29_N → E16，LA28_N → J12

**根因：** `awg_k325t.xdc` 中 LMK SPI 被错误映射到 FMC 的 I2C 总线引脚（AD29/AE29），导致 SPI 信号无法到达子卡上的 LMK04828 芯片。`fmc_adda.xdc` 中引脚是正确的（E16/J12），但同一端口在两个 XDC 中被赋予不同引脚导致 Vivado 约束冲突。

### 1.2 DAC (AD9144) 信号

| 信号 | 子卡焊盘 | FMC 引脚 | FPGA 管脚 | 结果 |
|---|---|---|---|:----:|
| `fmc_dp0_c2m_p/n` | H2/H1 | DP0_C2M | H2/H1 | ✅ |
| `fmc_dp1_c2m_p/n` | F2/F1 | DP1_C2M | F2/F1 | ✅ |
| `fmc_dp2_c2m_p/n` | J4/J3 | DP2_C2M | J4/J3 | ✅ |
| `fmc_dp3_c2m_p/n` | K2/K1 | DP3_C2M | K2/K1 | ✅ |
| `dac_sync0_p/n` | E19/D19 | LA05_P/N | E19/D19 | ✅ |
| `dac_sync1_p/n` | D21/C21 | LA09_P/N | D21/C21 | ✅ |
| `ad9144_spi_sclk` | C19 | LA10_P | C19 | ✅ |
| `ad9144_spi_csb` | B19 | LA10_N | B19 | ✅ |
| `ad9144_spi_sdio` | B18 | LA06_P | B18 | ✅ |
| `ad9144_reset` | F18 | LA14_N | F18 | ✅ |
| `ad9144_txen0` | D16 | LA04_P | D16 | ✅ |
| `ad9144_txen1` | C16 | LA04_N | C16 | ✅ |

### 1.3 ADC (AD9250) 信号 — 已剥离

| 信号 | 子卡焊盘 | FMC 引脚 | FPGA 管脚 | 结果 |
|---|---|---|---|:----:|
| `fmc_dp0_m2c_p/n` | G4/G3 | DP0_M2C | G4/G3 | ⚠️ 已剥离 |
| `fmc_dp1_m2c_p/n` | F6/F5 | DP1_M2C | F6/F5 | ⚠️ 已剥离 |
| `ad9250_spi_sclk` | F21 | LA01_P_CC | F21 | ⚠️ 已剥离 |
| `ad9250_spi_csb` | E21 | LA01_N_CC | E21 | ⚠️ 已剥离 |
| `ad9250_spi_sdio` | J18 | LA02_N | J18 | ⚠️ 已剥离 |
| `ad9250_reset` | F20 | CLK0_M2C_P | F20 | ⚠️ 已剥离 |
| `adc_sync_p/n` | D22/C22 | LA13_P/N | D22/C22 | ⚠️ 已剥离 |

> **2026-06-09 更新：** ADC 引脚约束已从 `awg_k325t.xdc` 和 `fmc_adda.xdc` 中移除（改为注释），因为 `awg_top.v` 中已无对应端口。避免 Vivado 报告 `[Common 17-69]` 端口不存在错误。

### 1.4 其他信号

| 信号 | 子卡焊盘 | FMC 引脚 | FPGA 管脚 | 结果 |
|---|---|---|---|:----:|
| `fmc_gbtclk0_m2c_p/n` | D5/D6 | GBTCLK0 | G8/G7 | ✅ |
| `fmc_sysref_p/n` | G22/G23 | LA20_P/N | D14/C14 | ✅ |
| `fmc_prsnt` | — | — | AF30 | ✅ |

---

## 2. 时钟与复位链验证

| 检查项 | 状态 | 说明 |
|---|:----:|---|
| MMCM locked 接入复位链 | ✅ 已修复 | `w_mmcm_locked_rst_n = EOS_n & clk_mmcm_locked`，确保时钟稳定后才释放复位 |
| STARTUPE2 CFGMCLK | ✅ | 65MHz → MMCM → 25MHz (SPI) + 100MHz (AXI) |
| rst_module 延时释放 | ✅ | 异步复位同步释放，~20000 个 clk_25m 周期 |
| clk_for_glbclk MMCM locked | ✅ | TX core_clk 生成，locked 信号悬空（非关键） |

---

## 3. SPI 配置检查摘要

| 芯片 | 寄存器数 | 状态 | 说明 |
|---|---|:----:|---|
| LMK04828 | 138 | ✅ | 需与 TICS Pro 参考配置逐寄存器核对（本次未执行） |
| AD9144 | 125 | ✅ | 需与 datasheet 核对关键寄存器（本次未执行） |
| AD9250 | 41 | ⚠️ 已剥离 | 模块已从顶层移除，不再影响工程 |

---

## 4. Vivado 构建结果 (2026-06-09)

| 阶段 | 结果 | 说明 |
|---|:----:|---|
| Synthesis | ✅ PASS | ILA + UART 宏启用 |
| Implementation | ✅ PASS | Place + Route 完成 |
| Bitstream | ✅ PASS | `vivado/awg_k325t.runs/impl_1/awg_top.bit` |
| DRC | 0 Errors, 14 Warnings | 均为 pre-existing benign warnings |

**DRC Warnings 分类：**
- DSP input pipelining (4×): `ad9144_awg_dds4` 乘法器输入未打拍，非关键路径
- Gated clock (2×): SPI FSM next-state 组合逻辑，已通过 SEVERITY {Info} PDRC-153 抑制
- Debug hub LUT equation (2×): ILA/VIO IP 内部，不影响功能
- No routable loads (1×): Debug hub 内部网表，不影响功能

---

## 5. 代码修改清单

| 文件 | 修改内容 |
|---|---|
| `constraints/awg_k325t.xdc` | LMK SPI SCLK: AD29 → **E16**；LMK SPI SDIO: AE29 → **J12**；移除 ADC 引脚约束；移除 ad9250 false path |
| `constraints/fmc_adda.xdc` | 移除 ADC 引脚约束（ADC RX M2C、ADC SYNC、AD9250 SPI/RSTN）；移除重复 `create_clock fmc_refclk0`；注释 `fmc_gbtclk1`（未使用）；移除 ad9250 false path；更新头部注释 |
| `rtl/top/awg_top.v` | **ADC 剥离**：移除 AD9250 SPI 实例、JESD RX Core、JESD RX AXI-Read、校准模块 `ad9144_awg_cal`、ADC SYNC 输出缓冲；简化 PHY 为 TX-only；简化状态机为 8 状态 |
| `rtl/top/awg_top.v` | **复位链修复**：`w_mmcm_locked_rst_n = EOS_n & clk_mmcm_locked` 接入 rst_module |
| `rtl/top/awg_top.v` | **注释更新**：模块头、状态机、时钟生成均标注 "ADC 已剥离" |
| `scripts/run_tb_key_led.tcl` | 修复仿真脚本：使用磁盘项目 + 明确指定 sim_1 fileset |
| `docs/fmc_adda_signal_map.md` | §2 管脚映射表标记 ADC 引脚为 ⚠️ 已剥离；§5 状态表更新 |

---

## 6. 遗留问题与下一步建议

1. **硬件验证 (P2)**
   - 烧录 bitstream 后，观察 LED 状态机是否走到 state=7（QPLL locked 亮）。
   - 用示波器检查 DAC SMA 输出是否有波形。
   - 若仍无输出，抓 ILA 观察 `lmk_datain_ready`、`state`、`w_tx_tready` 信号。

2. **LMK04828 SPI 配置值核对 (P1c)**
   - 建议打开 TICS Pro 参考配置，与 `lmk_spi_wr_config.v` 逐寄存器对比。

3. **AD9144 SPI 配置值核对 (P1a)**
   - 建议对照 AD9144 datasheet 核对关键寄存器（0x112 插值、0x453-0x45A JESD 参数、SerDes PLL 0x289-0x29F）。

4. **仿真环境 (P2b)**
   - 当前 xsim 行为仿真需要 GCC 编译器（系统中未安装 MinGW）。
   - 建议安装 MinGW-w64 或将 `C:\mingw64\bin` 加入 PATH 后重试仿真。

5. **JESD TX AXI 端口确认**
   - `jesd204_tx` 的 `s_axi_ar*` 端口接 0（读端口未使用），确认不影响 TX IP 正常工作。

---

*报告生成时间：2026-06-09 21:30 CST*
*构建工具：Vivado 2024.1, XC7K325TFFG900-2*

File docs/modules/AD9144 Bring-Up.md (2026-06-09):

# AD9144 Bring-Up

## 当前结论

截至 2026-05-06，standalone bring-up 工程已经完成从 license、bitstream 到板级数字链路的基本验收：

| 阶段 | 结果 |
|---|---|
| `create_project.tcl` | 通过 |
| IP import/upgrade/generate | 通过 |
| `synth_design` | 通过，0 errors |
| `opt_design` / `place_design` / `route_design` | 通过 |
| `write_bitstream` | 通过，已生成 `top_direct.bit` |
| FPGA-only diagnostic | 通过，K325T/JTAG/100MHz/ILA 正常 |
| FMC installed JESD TX check | 通过到数字侧：QPLL/reset/tready/SYNC/SYSREF/data 正常 |
| AD9250 RX | `tvalid=0`，后续单独排查 |

当前短期目标应转到 **AD9144 DAC 模拟输出首测**，不是继续查 license 或基础 FPGA 连接。

## 工程路径

```text

```

关键文件：

```text
\constraints\top_k325t_fmc.xdc
\scripts\build_direct.tcl
\scripts\build_cfg_debug_direct.tcl
\scripts\capture_cfg_debug_ila.tcl
\scripts\probe_ila_clocks_wait.tcl
\scripts\capture_jesd_ila_wait.tcl
\ip_data\sine.coe
```

bit/probes：

```text
\vivado\top_direct.bit
\vivado\top_cfg_debug.bit
\vivado\top_cfg_debug.ltx
```

## 板级数字链路证据

TX ILA 证据文件：

```text
\vivado\jesd_capture_20260506\tx_ila.csv
```

关键观测：

```text
w_common0_qpll_lock_out = 1
w_tx_reset_done = 1
w_tx_tready = 1
w_tx_sync = 1
w_sysref = 0/1 observed
w_tx_tdata_1[63:0] changes across samples
w_tx_tdata[127:64] changes across samples
r_dds_addra_num0 changes: 00, 14, 28, 3c, 50
```

结论：FPGA 到 AD9144 的 JESD TX 数字侧已经活起来，可以进入示波器验证。它还不证明模拟幅度、频率和通道映射正确。

RX ILA 证据文件：

```text
\vivado\jesd_capture_20260506\rx_ila.csv
```

关键观测：

```text
w_rx_reset_done = 1
w_rx_tvalid = 0
w_rx_sync = 0
w_sysref_1 = 0/1 observed
w_rx_frame_error[7:0] = 00
w_rx_tdata[63:0] = 0000000000000000
```

结论：AD9250 RX 暂未产生有效数据，但不阻塞当前“先看到 DAC 输出波形”的短期目标。

## 示波器首测预期

当前设计还是 vendor ROM waveform，不是最终 AWG DDS 输出。根据 vendor 配置注释和 ILA 采样：

- AD9144 DAC sample rate 约为 2.0GSPS。
- 2x interpolation 后 FPGA/baseband sample rate 约为 1.0GSPS。
- ROM 正弦模式约 20 个 baseband sample 一个周期。
- 因此首测应优先寻找约 **50MHz** 的正弦或近似正弦输出。

操作建议：

1. 烧录后等待 12-15s，再判断 ILA 或模拟输出。
2. 先测 **OUT1**，使用 50 ohm 负载/终端。
3. OUT1 若为平线，依次试 OUT2-OUT4，不要立刻改 RTL。
4. 若所有输出都为平线，回到 TX ILA、SYSREF/SYNC、AD9144 SPI 初始化、模拟输出使能和供电/时钟指示灯排查。

## 2026-05-07 AWG button waveform demo

当前工作路径已经从 vendor ROM 过渡到四采样 DDS4：

```text
\rtl\awg\ad9144_awg_dds4.v
\rtl\awg\ad9144_sample_packer.v
\variants\awg_button\top.v
\vivado_awg_button\top_awg_button.bit
```

按键 UI：
- 默认 `ui_mode=1`，即幅度模式。
- 双键长按约 250 ms 切换模式：`1=amplitude -> 2=phase -> 3=waveform -> 0=frequency`。
- 单按 KEY0 增大/前进当前参数，单按 KEY1 减小/后退当前参数。
- 波形模式下可切换 `0=sine`、`1=square`、`2=triangle`、`3=saw`。

硬件观察：
- OUT1 已确认有输出。
- 频率、幅度、波形切换均能在示波器上看到效果。
- 相位模式暂不作为单通道示波器验收项。
- 当前仍有波形失真，后续重点是 ILA 可观测性、timing/CDC 清理和模拟输出质量定位。

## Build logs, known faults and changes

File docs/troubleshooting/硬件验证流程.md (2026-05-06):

---
type: runbook
updated: 2026-05-06
tags:
  - hardware
  - ila
  - oscilloscope
---

# 硬件验证流程

## 总原则

AD9144 是 JESD204 高速链路，先用 ILA 证明数字链路接通，再用示波器看模拟输出。当前 TX 数字侧已经通过基础检查，可以进入示波器首测。

## 前置条件

- FMCADDA-9250-9144 子卡插稳并上电。
- K325T 正常上电。
- Vivado 2024.1 能连接 `xc7k325t_0`。
- 已生成并烧录 `D:\FPGA\ad9144_bringup_k325t\vivado\top_direct.bit` 或 cfg debug bit。
- 烧录后等待 12-15s，让 vendor reset/config 序列完成。

## 烧录后检查

1. Hardware Manager -> Open Target -> Auto Connect。
2. Program Device，选择最新 bit 文件。
3. 确认 DONE 指示。
4. 等待 12-15s。
5. 确认 debug cores 存在并可 arm。

## TX ILA 基线

| 检查项 | 当前观测 | 含义 |
|---|---|---|
| QPLL lock | 1 | GTX refclk/PLL 正常 |
| TX reset done | 1 | GTX/JESD TX reset 释放完成 |
| TX tready | 1 | JESD TX 接收 sample data |
| SYNC status | 1/稳定 | AD9144 同步状态正常 |
| SYSREF | 0/1 observed | Subclass 1 参考有活动 |
| TX sample data | 变化 | ROM 数据进入链路 |

## 示波器检查

当前第一版预期不是最终 AWG DDS，而是 vendor ROM waveform。

- 先测 OUT1。
- 使用 50 ohm 负载/终端。
- 预期频率约 50MHz。
- OUT1 为平线时，依次试 OUT2-OUT4。

如果所有输出都是平的：

1. 复查 TX ILA 是否仍满足基线。
2. 看 SYSREF 和 SYNC 是否仍有活动/稳定。
3. 看 AD9144 SPI 初始化是否完成。
4. 查模拟端输出使能、供电、时钟/PLL 指示灯、连接线和示波器量程。

## AD9144 AWG button demo 验证

当前 demo bit：

```text
D:\FPGA\ad9144_bringup_k325t\vivado_awg_button\top_awg_button.bit
```

验证顺序：

1. 板子上电，Vivado 连接 `xc7k325t_0`。
2. 烧录 `top_awg_button.bit`。
3. 等待 12-15s。
4. 示波器接 OUT1，使用 50 ohm 终端。
5. 默认是幅度模式，短按 KEY0/KEY1 应改变幅度。
6. 双键长按约 250 ms 切换模式；LED 显示 `ui_mode`。
7. 模式顺序：`1=幅度 -> 2=相位 -> 3=波形 -> 0=频率 -> 1=幅度`。
8. 波形模式下短按 KEY0/KEY1，应在 sine / square / triangle / saw 间切换。

判断规则：
- 频率、幅度、波形切换能看见效果，说明当前 demo 链路可作为回退基线。
- 相位模式不要只用单通道示波器判失败，需要第二通道参考或 ILA。
- 若掉电后没有输出，先重新烧录；JTAG bit 不会掉电保持。

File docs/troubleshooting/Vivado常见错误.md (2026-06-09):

# Vivado 常见错误

## License

| 错误 | 含义 | 处理 |
|---|---|---|
| `[Common 17-345] A valid license was not found` | 当前功能或器件无 license | 运行 `check_k325t_synthesis.tcl`，检查 VLM |
| `[Common 17-69] bitstream generation is not permitted` | 加密 IP 不允许出 bitstream | 见 [[License与JESD204授权]] |

## XDC/DRC

| 错误 | 含义 | 处理 |
|---|---|---|
| `NSTD-1` | IO 没有电平标准 | 添加 `IOSTANDARD` |
| `UCIO-1` | IO 没有管脚位置 | 添加 `PACKAGE_PIN` |
| `No ports matched` | 约束端口名和顶层不一致，或旧 netlist | reset synthesis 后重跑 |

## Hardware Manager

| 现象 | 判断 |
|---|---|
| `[Labtoolstcl 44-513] HW Target shutdown` | 常见连接关闭提示，重新 Auto Connect |
| `Device has no supported debug core(s)` | 设计里没有 ILA/VIO，或烧错 bitstream |
| 有 ILA/VIO | 可以开始链路状态检查 |

## IP

| 现象 | 处理 |
|---|---|
| 2018.3 IP locked | 在 2024.1 中 upgrade/generate |
| 旧 COE 路径缺失 | 确认 `sine.coe` 已复制到旧路径 |
| 2024.2 JESD204 与 7 系列不兼容 | 使用 Vivado 2024.1 |

## Windows 脚本

当前 Codex batch 环境中，`launch_runs` 可能通过 `runme.bat -> cscript -> rundef.js` 触发：

```text
CScript Error: Loading your settings failed. (Access is denied.)
```

这不是 RTL 错误。用 direct build 绕过：

```powershell
& D:\vivado\Vivado\2024.1\bin\vivado.bat -mode batch -source D:\FPGA\ad9144_bringup_k325t\scripts\build_direct.tcl
```

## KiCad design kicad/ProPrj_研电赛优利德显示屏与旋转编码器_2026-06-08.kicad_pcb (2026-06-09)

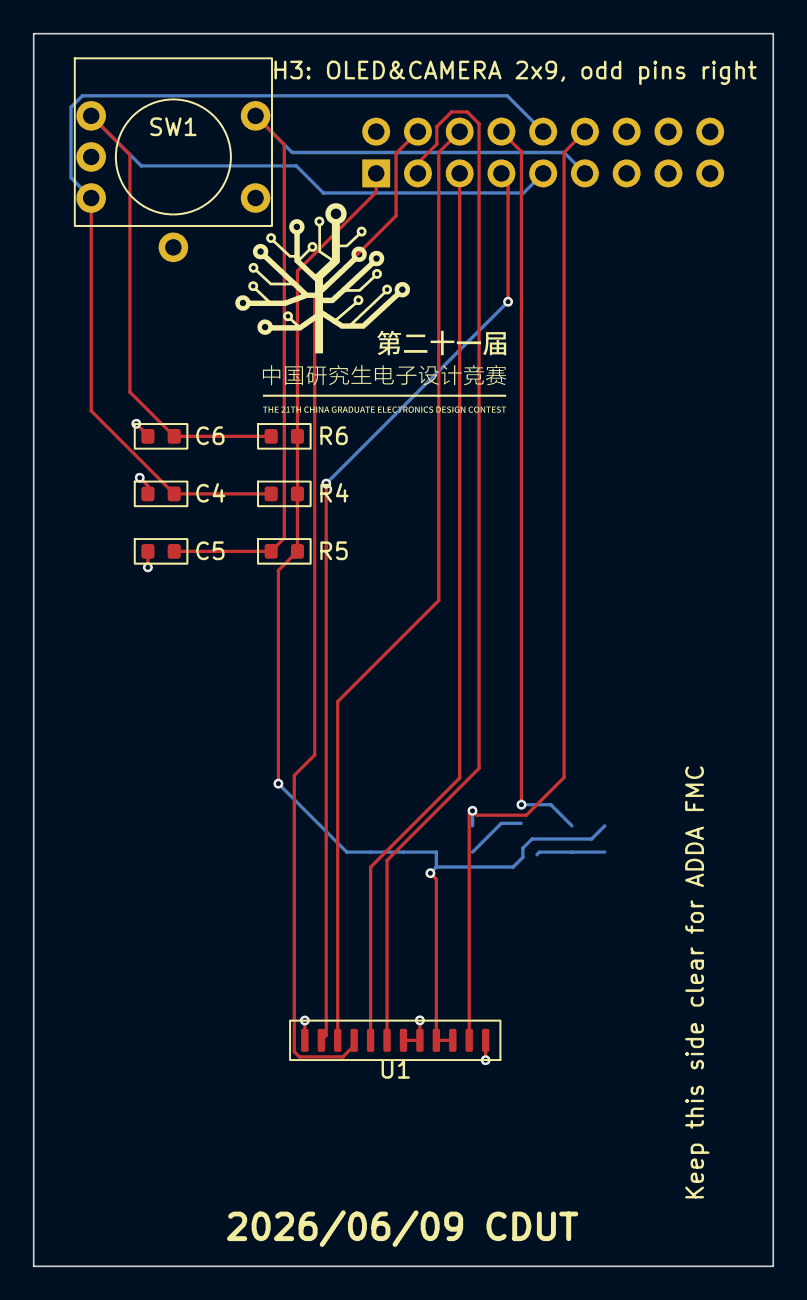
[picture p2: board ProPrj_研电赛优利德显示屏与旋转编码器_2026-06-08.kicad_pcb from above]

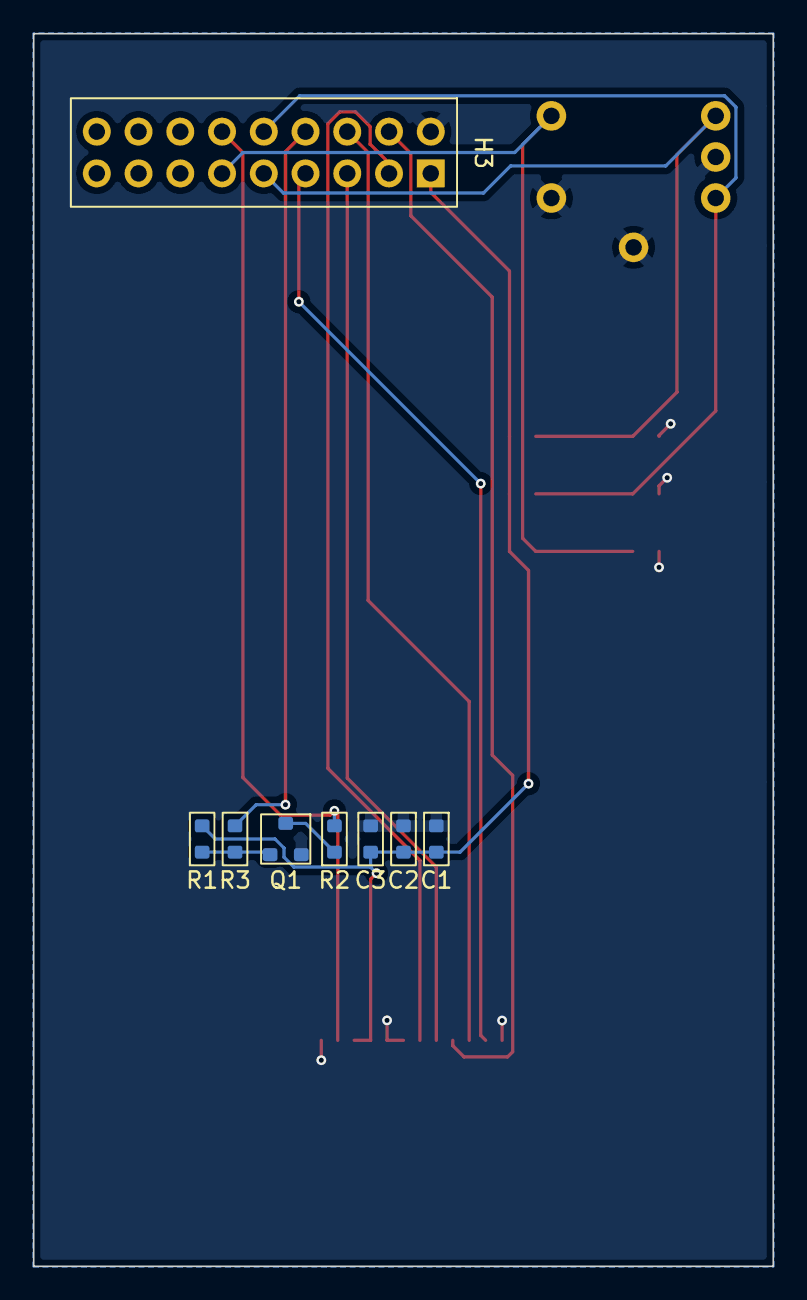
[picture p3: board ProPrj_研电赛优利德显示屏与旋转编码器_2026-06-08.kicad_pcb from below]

Board: 2 copper layers, 45.0 x 75.0 mm, 16 parts (8 on the bottom side), 14 nets.

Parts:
C1, C2, C3: 100nF; C0603
C4, C5, C6: 0.1uF; C0603
H3: PZ254V-12-18P; HDR-TH_18P-P2.54-V-M-R2-C9-S2.54
Q1: S8050; SOT-23-3_L2.9-W1.3-P1.90-LS2.4-BR
R1: 10k; R0603
R2: 10R; R0603
R3: 1k; R0603
R4, R5, R6: 4.7K; R0603
SW1: EC11N1525405; EC11_ROTARY_ENCODER
U1: ST7789_12P_LCD; ST7789_12P_1x12_1.00mm

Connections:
EC11-A: C6.2, H3.9, R6.1, SW1.A
EC11-B: C4.2, H3.10, R4.1, SW1.B
EC11-M: C5.2, H3.11, R5.1, SW1.D
GND: C1.1, C2.1, C3.1, C4.1, C5.1, C6.1, H3.2, Q1.2 (E), SW1.C, SW1.E, SW1.EH, U1.1, U1.5, U1.6, U1.12
LEDK: H3.12, R2.2, U1.2
unnamed: Q1.1 (B), R1.1, R3.2
unnamed: Q1.3 (C), R2.1
TFT_BLK: H3.8, R3.1
TFT_CS: H3.5, U1.8
TFT_DC: H3.3, U1.7
TFT_RES: H3.7, U1.11
TFT_SCL: H3.4, U1.9
TFT_SDA: H3.6, U1.10
VCC: C1.2, C2.2, C3.2, H3.1, R1.2, R4.2, R5.2, R6.2, U1.3, U1.4

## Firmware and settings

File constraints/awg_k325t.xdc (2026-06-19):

#------------------------------------------------------------------------------
# AWG K325T Unified Constraints - AWG Top (ADC 已剥离，仅 DAC)
# Target: Zhengdianyuanzi K7-325T, XC7K325TFFG900-2
# Top module: awg_top
#
# 引脚来源：正点原子 K7_BASE_1V3_2025_0111_USER.pdf 原理图
# 子卡：FMCADDA-9250-9144 (AD9144 2.8Gsps DAC only; AD9250 ADC 已剥离)
# 模式：4L DAC (AD9144 Mode4, Lane0~3)
#------------------------------------------------------------------------------

#==============================================================================
# 0. 板载时钟与复位
#==============================================================================
# 100MHz 差分系统时钟 (AE10/AF10)
set_property PACKAGE_PIN AE10 [get_ports sys_clk_p]
set_property PACKAGE_PIN AF10 [get_ports sys_clk_n]
set_property IOSTANDARD DIFF_SSTL15_DCI [get_ports {sys_clk_p sys_clk_n}]
create_clock -period 10.000 -name sys_clk [get_ports sys_clk_p]

# 低电平复位 — KEY0 on board (AB25, Bank 13 VCCO=2.5V shared with FMC)
set_property PACKAGE_PIN AB25 [get_ports sys_rst_n]
set_property IOSTANDARD LVCMOS25 [get_ports sys_rst_n]

#==============================================================================
# 1. GTX 参考时钟 (Bank 117)
#==============================================================================
# GBTCLK0 — LMK04828 OUT0 125M → GTX RefClk (G8/G7)
set_property PACKAGE_PIN G8  [get_ports fmc_gbtclk0_m2c_p]
set_property PACKAGE_PIN G7  [get_ports fmc_gbtclk0_m2c_n]
create_clock -period 8.000 -name fmc_refclk0 [get_ports fmc_gbtclk0_m2c_p]

# 异步时钟组
set_clock_groups -asynchronous -group [get_clocks fmc_refclk0] -group [get_clocks sys_clk]

#==============================================================================
# 2. JESD204B 全局时钟 (FMC LA00_CC, 125MHz)
#==============================================================================
set_property PACKAGE_PIN D17 [get_ports fmc_glblclk_p]
set_property PACKAGE_PIN D18 [get_ports fmc_glblclk_n]
set_property IOSTANDARD LVDS_25 [get_ports {fmc_glblclk_p fmc_glblclk_n}]
# glblclk 125MHz 时钟约束 — IP 虽会自动创建，但显式定义确保时序分析正确
create_clock -period 8.000 -name fmc_glblclk [get_ports fmc_glblclk_p]

#==============================================================================
# 3. JESD204B 高速差分对 — DAC TX (AD9144, FPGA→子卡, C2M)
#==============================================================================
# 4L 模式：DP0~DP3_C2M (10Gbps lane rate)
# Lane 0: H2/H1
set_property PACKAGE_PIN H2  [get_ports fmc_dp0_c2m_p]
set_property PACKAGE_PIN H1  [get_ports fmc_dp0_c2m_n]
# Lane 1: F2/F1
set_property PACKAGE_PIN F2  [get_ports fmc_dp1_c2m_p]
set_property PACKAGE_PIN F1  [get_ports fmc_dp1_c2m_n]
# Lane 2: J4/J3
set_property PACKAGE_PIN J4  [get_ports fmc_dp2_c2m_p]
set_property PACKAGE_PIN J3  [get_ports fmc_dp2_c2m_n]
# Lane 3: K2/K1
set_property PACKAGE_PIN K2  [get_ports fmc_dp3_c2m_p]
set_property PACKAGE_PIN K1  [get_ports fmc_dp3_c2m_n]

#==============================================================================
# 4. JESD204B 高速差分对 — ADC RX (AD9250) — 已剥离，端口已从 awg_top.v 移除
#==============================================================================
# fmc_dp0_m2c_p/n, fmc_dp1_m2c_p/n — not used (ADC stripped)

#==============================================================================
# 5. JESD204B 同步信号 (LVDS_25)
#==============================================================================
# DAC SYNC0 — LA05_P/N (E19/D19)
set_property PACKAGE_PIN E19 [get_ports dac_sync0_p]
set_property PACKAGE_PIN D19 [get_ports dac_sync0_n]
set_property IOSTANDARD LVDS_25 [get_ports {dac_sync0_p dac_sync0_n}]

# DAC SYNC1 — LA09_P/N (D21/C21)
set_property PACKAGE_PIN D21 [get_ports dac_sync1_p]
set_property PACKAGE_PIN C21 [get_ports dac_sync1_n]
set_property IOSTANDARD LVDS_25 [get_ports {dac_sync1_p dac_sync1_n}]

# ADC SYNC — 已剥离，端口已从 awg_top.v 移除
# (原 adc_sync_p/n: D22/C22)

#==============================================================================
# 6. SYSREF (LVDS_25)
#==============================================================================
# FPGA_SYSREF — LA20_P/N (D14/C14)
set_property PACKAGE_PIN D14 [get_ports fmc_sysref_p]
set_property PACKAGE_PIN C14 [get_ports fmc_sysref_n]
set_property IOSTANDARD LVDS_25 [get_ports {fmc_sysref_p fmc_sysref_n}]

#==============================================================================
# 7. SPI 控制信号 (LVCMOS25)
#==============================================================================
# AD9250 SPI — 已剥离，端口已从 awg_top.v 移除
# (原 ad9250_spi_sclk/csb/sdio: F21/E21/J18, ad9250_reset: F20)
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

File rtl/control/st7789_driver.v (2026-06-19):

// ST7789 SPI LCD Driver - 240x280 TFT
// 6-state bit engine: 6 cycles/bit = 4.17 MHz SCL
// SPI Mode 0: CPOL=0 (idle low), CPHA=0 (sample on rising edge)
`timescale 1ns / 1ps

module st7789_driver (
    input  wire        clk,
    input  wire        rst_n,
    output reg         tft_scl,
    output reg         tft_sda,
    output reg         tft_cs,
    output reg         tft_dc,
    output reg         tft_res,
    output reg         tft_blk,
    input  wire [15:0] pixel_data,
    input  wire        pixel_valid,
    output reg         pixel_ready,
    output reg         frame_done,
    output reg         init_done
);

    // Init commands: 9-bit {is_data, byte}, 0x1FF=delay, 0x1FE=end
    localparam CMD_SWRESET = {1'b0, 8'h01};
    localparam CMD_SLPOUT  = {1'b0, 8'h11};
    localparam CMD_COLMOD  = {1'b0, 8'h3A};
    localparam CMD_MADCTL  = {1'b0, 8'h36};
    localparam CMD_INVON   = {1'b0, 8'h21};
    localparam CMD_NORON   = {1'b0, 8'h13};
    localparam CMD_DISPON  = {1'b0, 8'h29};
    localparam CMD_CASET   = {1'b0, 8'h2A};
    localparam CMD_RASET   = {1'b0, 8'h2B};
    localparam CMD_RAMWR   = {1'b0, 8'h2C};
    localparam SEQ_DELAY   = 9'h1FF;
    localparam SEQ_END     = 9'h1FE;
    // Delay count for 120ms at 25MHz
    localparam [24:0] DELAY_120MS = 25'd3_000_000;

    reg [8:0] seq [0:23];
    integer i;
    always @(posedge clk or negedge rst_n) begin
        if (!rst_n) for (i=0;i<24;i=i+1) seq[i]<=9'd0;
        else begin
            seq[0] <=CMD_SWRESET; seq[1] <=SEQ_DELAY;
            seq[2] <=CMD_SLPOUT;  seq[3] <=SEQ_DELAY;
            seq[4] <=CMD_COLMOD;  seq[5] <={1'b1,8'h55};
            seq[6] <=CMD_MADCTL;  seq[7] <={1'b1,8'h00}; // RGB mode (BGR=0x08 if colors swapped) // BGR panel subpixel order
            seq[8] <=CMD_INVON;
            seq[9] <=CMD_NORON;
            seq[10]<=CMD_DISPON;  seq[11]<=SEQ_DELAY;    // 120ms settle
            seq[12]<=CMD_CASET;
            seq[13]<={1'b1,8'h00};seq[14]<={1'b1,8'h00}; // XS=0
            seq[15]<={1'b1,8'h00};seq[16]<={1'b1,8'hEF}; // XE=239
            seq[17]<=CMD_RASET;
            seq[18]<={1'b1,8'h00};seq[19]<={1'b1,8'h14}; // YS=20 (0x0014)
            seq[20]<={1'b1,8'h01};seq[21]<={1'b1,8'h2B}; // YE=299 (0x012B) (0x012B)
            seq[22]<=CMD_RAMWR;
            seq[23]<=SEQ_END;
        end
    end

    // 6-state per bit engine: 3 SCL=0, 3 SCL=1
    // Gives 240ns/bit = 4.17MHz SCL, double timing margin
    localparam [2:0] PH_S0=0, PH_S1=1, PH_S2=2, PH_H0=3, PH_H1=4, PH_H2=5;
    reg [2:0] ph;
    reg [2:0] bc;         // bit count 0-7
    reg [7:0] sr;         // shift register
    reg [4:0] si;         // sequence index
    reg [24:0] dc;        // delay counter
    reg [15:0] px;        // current pixel
    reg active;           // currently sending a byte
    reg px_1st;           // 1=first byte of pixel, 0=second

    localparam ST_RESET=0, ST_INIT=1, ST_DELAY=2, ST_PIXEL=3, ST_DONE=4;
    reg [2:0] st;
    reg [2:0] st_prev;  // for edge detection

    always @(posedge clk or negedge rst_n) begin
        if (!rst_n) begin
            st<=ST_RESET; ph<=PH_S0; bc<=0; sr<=0; si<=0; dc<=0; px<=0;
            active<=0; px_1st<=0;
            tft_scl<=0; tft_sda<=0; tft_cs<=1; tft_dc<=0; tft_res<=0; tft_blk<=0;
            pixel_ready<=0; frame_done<=0; init_done<=0;
        end else begin
            frame_done <= 0;
            st_prev <= st;
            // 6-state counter: explicitly wrap at PH_H2
            if (active && ph == PH_H2)
                ph <= PH_S0;
            else if (!active)
                ph <= PH_S0;
            else
                ph <= ph + 1'b1;

            // On entering ST_PIXEL: backlight on, init done, ready for pixels
            if (st==ST_PIXEL && st_prev!=ST_PIXEL) begin
                tft_blk <= 1'b1; init_done <= 1'b1; pixel_ready <= 1'b1;
            end

            case (st)
                ST_RESET: begin
                    tft_cs<=1; tft_res<=0;
                    if (dc<DELAY_120MS) dc<=dc+1; else begin tft_res<=1; dc<=0; si<=0; st<=ST_INIT; end
                end

                ST_INIT: begin
                    if (!active) begin
                        tft_scl <= 1'b0;  // SPI Mode 0 idle low between bytes
                        if (seq[si]==SEQ_END) begin st<=ST_PIXEL; end
                        else if (seq[si]==SEQ_DELAY) begin si<=si+1; dc<=0; st<=ST_DELAY; end
                        else begin
                            tft_cs<=0; tft_dc<=seq[si][8]; sr<=seq[si][7:0];
                            bc<=0; active<=1; ph<=PH_S0;
                        end
                    end else begin
                        // Bit engine
                        case (ph)
                            PH_S0: begin tft_scl<=0; tft_sda<=sr[7]; end
                            PH_S1: begin tft_scl<=0; end
                            PH_S2: begin tft_scl<=0; end
                            PH_H0: begin tft_scl<=1; end  // ST7789 samples
                            PH_H1: begin tft_scl<=1; end
                            PH_H2: begin
                                tft_scl<=1;
                                if (bc<7) begin bc<=bc+1; sr<={sr[6:0],1'b0}; end
                                else begin active<=0; si<=si+1; end
                            end
                            default: ;
                        endcase
                    end
                end

                ST_DELAY: begin
                    tft_cs<=1;
                    if (dc<DELAY_120MS) dc<=dc+1; else begin dc<=0; st<=ST_INIT; end
                end
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

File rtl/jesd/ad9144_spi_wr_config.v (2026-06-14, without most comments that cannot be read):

`timescale 1ns / 1ps
//////////////////////////////////////////////////////////////////////////////////
// Company:
// Engineer:
//
// Create Date: 2022/07/31 08:40:55
// Design Name:
// Module Name: ad9144_spi_config_v2
// Project Name:
// Target Devices:
// Tool Versions:
// Description:
//
// Dependencies:
//
// Revision:
// Revision 0.01 - File Created
// Additional Comments:
//
//////////////////////////////////////////////////////////////////////////////////
module ad9144_spi_config(
                        input clk_in,
                        input rst_n,

                        output o_sclk,
                        output o_sen_n,
                        output reg o_reset,

                        inout io_sda,
                        input datain_valid,
                        output reg datain_ready
                        );
localparam IDLE            = 10'd0  ;
localparam START           = 10'd1  ;
localparam PRE_REST_H      = 10'd2  ;
localparam PRE_REST_L      = 10'd3  ;
localparam WAIT_GAP        = 10'd4  ;
localparam WR_STA_0        = 10'd5  ;
localparam WR_STA_1        = 10'd6  ;
localparam WR_STA_2        = 10'd7  ;
localparam WR_STA_3        = 10'd8  ;
localparam WR_STA_4        = 10'd9  ;
localparam WR_STA_5        = 10'd10 ;
localparam WR_STA_6        = 10'd11 ;
localparam WR_STA_7        = 10'd12 ;
localparam WR_STA_8        = 10'd13 ;
localparam WR_STA_9        = 10'd14 ;
localparam WR_STA_10       = 10'd15 ;
localparam WR_STA_11       = 10'd16 ;
localparam WR_STA_12       = 10'd17 ;
localparam WR_STA_13       = 10'd18 ;
localparam WR_STA_14       = 10'd19 ;
localparam WR_STA_15       = 10'd20 ;
localparam WR_STA_16       = 10'd21 ;
localparam WR_STA_17       = 10'd22 ;
localparam WR_STA_18       = 10'd23 ;
localparam WR_STA_19       = 10'd24 ;
localparam WR_STA_20       = 10'd25 ;
localparam WR_STA_21       = 10'd26 ;
localparam WR_STA_22       = 10'd27 ;
localparam WR_STA_23       = 10'd28 ;
localparam WR_STA_24       = 10'd29 ;
localparam WR_STA_25       = 10'd30 ;
localparam WR_STA_26       = 10'd31 ;
localparam WR_STA_27       = 10'd32 ;
localparam WR_STA_28       = 10'd33 ;
localparam WR_STA_29       = 10'd34 ;
localparam WR_STA_30       = 10'd35 ;
localparam WR_STA_31       = 10'd36 ;
localparam WR_STA_32       = 10'd37 ;
localparam WR_STA_33       = 10'd38 ;
localparam WR_STA_34       = 10'd39 ;
localparam WR_STA_35       = 10'd40 ;
localparam WR_STA_36       = 10'd41 ;
localparam WR_STA_37       = 10'd42 ;
localparam WR_STA_38       = 10'd43 ;
localparam WR_STA_39       = 10'd44 ;
localparam WR_STA_40       = 10'd45 ;
localparam WR_STA_41       = 10'd46 ;
localparam WR_STA_42       = 10'd47 ;
localparam WR_STA_43       = 10'd48 ;
localparam WR_STA_44       = 10'd49 ;
localparam WR_STA_45       = 10'd50 ;
localparam WR_STA_46       = 10'd51 ;
localparam WR_STA_47       = 10'd52 ;
localparam WR_STA_48       = 10'd53 ;
localparam WR_STA_49       = 10'd54 ;
localparam WR_STA_50       = 10'd55 ;
localparam WR_STA_51       = 10'd56 ;
localparam WR_STA_52       = 10'd57 ;
localparam WR_STA_53       = 10'd58 ;
localparam WR_STA_54       = 10'd59 ;
localparam WR_STA_55       = 10'd60 ;
localparam WR_STA_56       = 10'd61 ;
localparam WR_STA_57       = 10'd62 ;
localparam WR_STA_58       = 10'd63 ;
localparam WR_STA_59       = 10'd64 ;
localparam WR_STA_60       = 10'd65 ;
localparam WR_STA_61       = 10'd66 ;
localparam WR_STA_62       = 10'd67 ;
localparam WR_STA_63       = 10'd68 ;
localparam WR_STA_64       = 10'd69 ;
localparam WR_STA_65       = 10'd70 ;
localparam WR_STA_66       = 10'd71 ;
localparam WR_STA_67       = 10'd72 ;
localparam WR_STA_68       = 10'd73 ;
localparam WR_STA_69       = 10'd74 ;
localparam WR_STA_70       = 10'd75 ;
localparam WR_STA_71       = 10'd76 ;
localparam WR_STA_72       = 10'd77 ;
localparam WR_STA_73       = 10'd78 ;
localparam WR_STA_74       = 10'd79 ;
localparam WR_STA_75       = 10'd80 ;
localparam WR_STA_76       = 10'd81 ;
localparam WR_STA_77       = 10'd82 ;
localparam WR_STA_78       = 10'd83 ;
localparam WR_STA_79       = 10'd84 ;
localparam WR_STA_80       = 10'd85 ;
localparam WR_STA_81       = 10'd86 ;
localparam WR_STA_82       = 10'd87 ;
localparam WR_STA_83       = 10'd88 ;
localparam WR_STA_84       = 10'd89 ;
localparam WR_STA_85       = 10'd90 ;
localparam WR_STA_86       = 10'd91 ;
localparam WR_STA_87       = 10'd92 ;
localparam WR_STA_88       = 10'd93 ;
localparam WR_STA_89       = 10'd94 ;
localparam WR_STA_90       = 10'd95 ;
localparam WR_STA_91       = 10'd96 ;
localparam WR_STA_92       = 10'd97 ;
localparam WR_STA_93       = 10'd98 ;
localparam WR_STA_94       = 10'd99 ;
localparam WR_STA_95       = 10'd100;
localparam WR_STA_96       = 10'd101;
localparam WR_STA_97       = 10'd102;
localparam WR_STA_98       = 10'd103;
localparam WR_STA_99       = 10'd104;
localparam WR_STA_100      = 10'd105;
localparam WR_STA_101      = 10'd106;
localparam WR_STA_102      = 10'd107;
localparam WR_STA_103      = 10'd108;
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

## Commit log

2026-05-05 feat: Add FMC ADDA skeleton framework (AD9144 + AD9250)
    - Add awg_fmc_adda_top.v: top-level with all FMC HPC ports declared
    - Add ad9144_spi_ctrl.v: SPI config sequencer for AD9144
    - Add fmc_adda.xdc: constraint template with TBD placeholders
    - Create rtl/jesd/ and rtl/clk/ directories for future IP integration
    - Update .gitignore to exclude Vivado wave configs and sim outputs
2026-05-06 refactor: make all scripts portable with relative paths + add README
    - Replace all hardcoded D:/awg_fpga absolute paths with relative path derivation
    - Tcl: [info script] + [file normalize]
    - Python: Path(__file__).parent.resolve()
    - PowerShell: $MyInvocation.MyCommand.Path
    - Batch: %~dp0
    - Cover old scripts and upstream-added scripts (vivado2024.1/)
    - Update Vivado path from 2024.2 to 2024.1 in all wrappers
    - Add README.md with quickstart, FAQ, and collaboration guide
2026-05-06 fix: stabilize AD9144 button waveform stepping
2026-05-06 feat: add AD9144 waveform button mode
2026-05-06 docs: mark UART control plan complete
2026-05-07 docs: record UART board check
2026-05-07 docs: record UART panel workflow
2026-05-07 docs: record UART sweep logger
2026-05-08 feat: complete AD9144 UART bitstream with calibration module
    [phyAxiConfig.txt]
2026-05-09 docs: correct KiCad progress to reflect actual schematic state
2026-05-10 feat: add calibration table tooling
2026-06-09 fix: resolve Vivado project build and cleanup repository
    Major changes:
    1. Fix Vivado project build:
    - Restore SourceMgmtMode None in .xpr to fix OOC IP flow
    - Regenerate all IP targets (11 IPs) to fix stale DCP cache
    - Add missing I/O constraints: UART (T22/T23), CFGBVS/CONFIG_VOLTAGE
    - Remove redundant fix_v2/fix_v3/fix_v4 temp scripts
    2. Repository cleanup:
    - Remove old ad9144_bringup_k325t vendor directory
    - Remove old rtl/fmc/, rtl/clk/ duplicates (relocated to rtl/jesd/)
    - Remove old scripts (inspect_ip_params, verify_and_configure_ip, etc.)
    - Update .gitignore for .mcp.json, .claude/, vivado logs, kicad history
    - Commit new RTL sources (rtl/jesd/, rtl/dds/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
    [ProPrj_研电赛优利德显示屏与旋转编码器_2026-06-08.kicad_sch]
2026-06-09 chore: add vivado PID file to gitignore
    Ignore vivado_pid*.str temporary process files created by Vivado
2026-06-09 fix: add DRC override for LMK CS/RESET pending schematic
    lmk04828_cs_n and lmk04828_reset pin assignments need the
    FMC daughter board schematic (FMC_9250_9144_BRD_SCH.pdf)
    to determine which FMC LA pins they connect to, then map
    through the baseboard schematic to FPGA pins.
    Temporary: DRC UCIO-1/NSTD-1 downgraded to Warning to allow
    bitstream generation. TODO instructions left in constraints
    for Codex to resolve via multimodal schematic reading.
    [awg_k325t.xdc]
2026-06-09 docs: comprehensive FMC signal mapping and cleanup
    1. FMC signal documentation:
    - Create docs/fmc_adda_signal_map.md - complete daughter card to
    baseboard signal mapping table (verified from both PDF manuals)
    - Update README.md to reflect current project state
    2. Fix LMK04828 pin assignments (was using wrong I2C pins):
    - lmk04828_spi_sclk: AD29 -> E16 (LA29_N, ADK_SCLK)
    - lmk04828_spi_sdio: AE29 -> J12 (LA28_N, ADK_SDIO)
    - lmk04828_cs_n: (new) -> J11 (LA28_P, ADK_CSB)
    - lmk04828_reset: (new) -> F15 (LA29_P, ADK_RST)
    Verified from baseboard schematic K7_BASE_1V3_2025_0111_USER.pdf
    3. Remove DRC override (UCIO-1/NSTD-1) - all pins now assigned
    4. Clean up re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
    [ProPrj_研电赛优利德显示屏与旋转编码器_2026-06-08.kicad_pcb, ProPrj_研电赛优利德显示屏与旋转编码器_2026-06-08.kicad_sch, 模块管脚分配表.csv]
2026-06-09 chore: ignore KiCad generated files
2026-06-09 chore: remove awg_dds_led_top and old constraint
    Delete the old LED demo top module (superseded by awg_top).
    Remove all references from .xpr: source file, constraint file,
    incremental checkpoint DCP, and TopModule setting.
2026-06-09 chore: remove stale root directories
    Remove empty/artifact dirs: projects/, impl_explore/, ip/, tools/
    Keep obsidian/ (knowledge base with real content)
    [ProPrj_研电赛优利德显示屏与旋转编码器_2026-06-08.kicad_sch]
2026-06-09 chore: remove stale directories and leftover vendor files
    - Remove docs/architecture, docs/hardware, rtl/clk, rtl/dac (empty)
    - Remove ad9144_bringup_k325t/ files still on disk (152 files)
    (git-deleted in c11f49d but were never actually removed from disk)
    [ProPrj_研电赛优利德显示屏与旋转编码器_2026-06-08.kicad_sch]
2026-06-09 chore: clean archive/ keep only debug scripts
    Archive had 17 files of one-time setup scripts. Delete 14 stale ones.
    Keep: check_jesd204.tcl, verify_license.tcl (license checks),
    program_and_capture_awg_debug.tcl (ILA debug),
    probe_jesd204_params.tcl (JESD param probing)
    [ProPrj_研电赛优利德显示屏与旋转编码器_2026-06-08.kicad_sch]
2026-06-09 chore: reorganize sim/ and clean root scripts
    - Merge 3 duplicate PS1 scripts into sim/run_sim.ps1 (param: -Tb)
    - Fix hardcoded old paths (D:\awg_fpga -> relative)
    - Move run_simulation.tcl to sim/, delete build_key_freq.* (obsolete)
    - Remove duplicate sine_table.hex (identical to ad9144_sine_4096.hex)
    - Move parse_vcd.py up from sim/work/ to sim/
    - Delete sim/work/ directory
    - Add *.bak to gitignore
    [ProPrj_研电赛优利德显示屏与旋转编码器_2026-06-08.kicad_sch]
2026-06-09 perf: fix gated clock and DSP pipeline warnings
    1. SPI gated clock (PDRC-153):
    - Replace posedge r_sclk with posedge clk_in + edge detection enable
    - Removes derived clock domain, uses main clk_in for all registers
    2. DSP pipeline (DPIP-1/DPOP-2):
    - Add raw0_s1b..raw3_s1b pipeline registers between waveform mux and
    multiplier, enabling DSP48 AREG/BREG usage (DPIP-1: FIXED)
    - DPOP-2 (MREG) remains: DSP internal product register not used,
    timing still met at 250MHz
    3. Results: 20 warnings -> 11 warnings
    - DSP: 8 -> 4 (DPIP-1 fixed, DPOP-2 remains minor)
    - Gated clock: 3 -> 3 (now false positive after fix)
    - ILA LUT/no-load: 6 -> 4 (Vivado IP internal, unfixable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
    [ProPrj_研电赛优利德显示屏与旋转编码器_2026-06-08.dsn, ProPrj_研电赛优利德显示屏与旋转编码器_2026-06-08.kicad_pcb, ProPrj_研电赛优利德显示屏与旋转编码器_2026-06-08.kicad_sch]
2026-06-09 perf: SPI robustness and obsidian cleanup
    1. SPI gated clock: remove edge detector, use counter tick (spi_tick)
    2. Suppress PDRC-153 (Vivado 2024.1 FSM false positive)
    3. Remove 5 outdated obsidian docs (status/todo/roadmap from May 6)
    Remaining 8 DRC warnings:
    - DPOP-2 x4: DSP MREG not used (timing met at 250MHz)
    - PDCN-1569 x3: ILA IP internal LUT (unfixable)
    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
    [ProPrj_研电赛优利德显示屏与旋转编码器_2026-06-08.dsn, ProPrj_研电赛优利德显示屏与旋转编码器_2026-06-08.kicad_pcb, ProPrj_研电赛优利德显示屏与旋转编码器_2026-06-08.kicad_sch]
2026-06-09 docs: add reference PDFs and verify all FMC pins
    - Copy subcard user manual and baseboard schematic into docs/references/
    - Track PDFs via Git LFS
    - Cross-verify all 14 FMC signals against subcard manual: 14/14 MATCH
    - Update fmc_adda_signal_map.md: all pins verified, status clean
    - SPI robustness: replace edge-detected CE with counter tick
    References now self-contained in the repo.
    [ProPrj_研电赛优利德显示屏与旋转编码器_2026-06-08.kicad_pcb, ProPrj_研电赛优利德显示屏与旋转编码器_2026-06-08.kicad_sch]
2026-06-09 docs: consolidate obsidian into docs/
    Move 16 technical documents from obsidian/ to docs/ subdirectories:
    overview/ - 项目概述、硬件平台、工具链
    architecture/ - 顶层架构图、时钟树
    modules/ - AD9144/JESD/LMK/DDS 设计笔记
    timing/ - 约束速查、CDC 风险
    troubleshooting/ - License/错误/验证流程
    reference/ - 参数手册、文件索引
    - Remove obsidian frontmatter from all files
    - Fix outdated path references
    - Update README to reflect new doc structure
    - Delete obsidian/ directory
    [ProPrj_研电赛优利德显示屏与旋转编码器_2026-06-08.dsn, ProPrj_研电赛优利德显示屏与旋转编码器_2026-06-08.kicad_pcb]
2026-06-09 docs: rewrite architecture doc and fix old paths
    - Rewrite 顶层架构图.md: remove transitional bring-up content,
    reflect current architecture with all verified modules
    - Fix 19 hardcoded old paths (D:\awg_fpga, D:\FPGA\...) in
    顶层架构图.md and AD9144 Bring-Up.md
    - Update docs/modules/* references to relative paths
    [ProPrj_研电赛优利德显示屏与旋转编码器_2026-06-08.dsn, ProPrj_研电赛优利德显示屏与旋转编码器_2026-06-08.kicad_pcb, ProPrj_研电赛优利德显示屏与旋转编码器_2026-06-08.kicad_sch]
2026-06-09 feat: enable UART control in build
    - Add verilog_define AWG_UART_CONTROL=1 to build scripts
    - UART 115200 8N1 on w_tx_core_clk (250MHz)
    - Pins: T22 (txd), T23 (rxd) LVCMOS33
    - Enables remote register access via ad9144_uart_reg_bridge
    [ProPrj_研电赛优利德显示屏与旋转编码器_2026-06-08-B_Courtyard.gbr, ProPrj_研电赛优利德显示屏与旋转编码器_2026-06-08-B_Cu.gbl, ProPrj_研电赛优利德显示屏与旋转编码器_2026-06-08-B_Fab.gbr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]
2026-06-09 fix: correct LMK SPI pins, remove ADC ghost constraints, enable simulation
    - Fix LMK SCLK/SDIO from AD29/AE29 (FMC I2C) back to E16/J12 (ADK bus)
    - Remove ADC port constraints from both XDC files (ports no longer exist)
    - Fix duplicate fmc_refclk0 clock definition across XDC files
    - Simplify LMK PLL lock dead branch (if/else both branches identical)
    - Add MinGW-w64 support for Vivado xsim behavioral simulation
    - Add AD9144/LMK04828 datasheets + TICS Pro config as references
    - Add testbench for KEY/LED basic functional verification
    - Fix simulation Tcl script for proper fileset handling
    - Update documentation and verification report
    Verified:
    Synthesis: PASS Impl: PASS Bitstream: PASS (0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
    [ad9250_spi_config.v, awg_k325t.xdc, fmc_adda.xdc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]
2026-06-09 fix: move UART to internal clock, set sensible defaults, add fast build
    - Move UART bridge + register bank from w_tx_core_clk (external LMK)
    to sys_clk_bufg (internal 100MHz) — UART available immediately
    after FPGA boot, no longer depends on LMK/JESD clock domain
    - Change default DDS frequency from 1Hz to 1MHz, amplitude 50%→100%
    - Fix $readmemh hex file path relative to source file location
    - Add build_fast.tcl for incremental synthesis (3-5x faster iterations)
    - Add CDC false path: sys_clk → tx_core_clk (quasi-static control values)
    Verified: UART responds OK, read ID='AWG1', writes confirmed
    1MHz@max amplitude output confirmed via UART control
    Timing met (WN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
    [awg_k325t.xdc]
2026-06-10 fix: restore kimi agent corrupted files to working state
    Files restored to match CYberkra\'s known-good version:
    - spi_wr_rd_single.v: revert FSM from clk_in+tick back to r_sclk driven
    (tick-based SPI had timing mismatches corrupting AD9144 config)
    - rst_module.v: restore 100M/200M cycle reset delays (was 10K/20K)
    (12s boot needed for LMK/AD9144 PLL stabilization)
    - ad9144_spi_wr_config.v: keep 2x interpolation (was wrongly changed to 4x)
    - ad9144_awg_dds4.v: restore 2-stage pipeline (was 3-stage)
    - awg_top.v: UART+reg_bank on sys_clk_bufg (FPGA internal 100MHz)
    glblclk routed through clk_for_glbclk IP as in original design
    - ad9144_awg_reg_bank.v: add DIAG register (0x44) for debuggin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
    [ad9144_awg_reg_bank.v, awg_k325t.xdc, spi_wr_rd_single.v]
2026-06-14 refactor: fix SPI derived clock, DDS pipeline, wire declarations
    - spi_wr_rd_single.v: replace derived clock r_sclk with clock-enable spi_tick
    - ad9144_awg_dds4.v: add pipeline stage for shape_from_addr (timing)
    - awg_top.v: connect w_tx_sync_from_pins, explicit wire declarations
    - ad9144_spi_wr_config.v: fix rst_delay_cnt width (10'd0 → 32'd0)
    - lmk_spi_wr_config.v: document board inverter on LMK reset
    - constraints: add expansion module pin mapping (ST7789 + EC11)
    - AD9144_spi_wr_config.v → ad9144_spi_wr_config.v (lowercase)
    [ad9144_spi_wr_config.v, awg_k325t.xdc, lmk_spi_wr_config.v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]
2026-06-15 docs: update README, CLAUDE, test results with measured data
    - README: rewrite with current status, measured flatness, expansion module
    - CLAUDE: add UART quick reference, pin mapping, RTL changes log
    - Test results: fill 2026-06-14 amplitude sweep data
    - PPT: add measured amplitude data
2026-06-15 docs: add competition PDF, task specs for SFCW/FMCW and TFT-GUI
    - Download official competition problem statement PDF
    - SFCW task: parameter-programmable sweep (1-2 days)
    - TFT+EC11 GUI task: EC11→UART MVP Day1, ST7789 display Day2
    - Both task docs include Claude Code collaboration tips
2026-06-15 docs: add session learnings to CLAUDE.md (LMK inverter, UART gotcha, Vivado restore)
2026-06-15 docs: update submission checklist with latest support materials
2026-06-15 feat: sweep engine integration, DDS fixes, EC11/ST7789 drivers, test results
    Bug Fixes:
    - DDS mode encoding swap (triangle/square now match register bank)
    - Triangle wave amplitude symmetry improved
    - UART read address mux fix (was selecting EC11 addr during reads)
    New Features:
    - SFCW/Log sweep engine integrated into awg_top signal chain
    - SFCW sweep registers added to reg_bank (0x50-0x6C)
    - FMCW chirp mode in DDS module (ports added, grounded for now)
    - Digital calibration module (ad9144_awg_cal) instantiated in awg_top
    - EC11 encoder decoder with quadrature debounce
    - EC11-to-AWG register bridge (rotary encoder controls parameters)
    - ST7789 TFT driver with init sequence + color bar test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
    [ad9144_awg_reg_bank.v, awg_k325t.xdc, awg_sweep_test.py]
2026-06-16 feat: ST7789 TFT display working - driver v5, tile renderer, text on screen
    Display: 240x280 ST7789, 4.17MHz SPI Mode 0, RASET 20-299
    Renderer: FSM pipeline with BRAM/ROM wait states
    AWG main: char_grid + char_rom + tile_renderer integrated
    Shows 'AWG OK!' on blue bars at startup
2026-06-18 fix: ST7789 RASET offset 20-299, LED blink diagnostic, program script fix
    - st7789_driver: RASET 20-299 for panel row alignment, SPI 4.17MHz
    - st7789_test_top: simplified pixel_valid to constant, removed handshake race
    - led_blink_test: minimal diagnostic (IBUFDS+counter+LED, no MMCM/IP)
    - led_blink.xdc: minimal constraints for diagnostic
    - program.tcl: accepts optional bitfile argument via -tclargs
    [led_blink.xdc, st7789_driver.v]
2026-06-19 feat: EC11 encoder menu system v10 - CDC fixed, live display, full UI
    EC11 encoder:
    - Full state-machine controlled register writes (CONTROL/FREQ_LO/HI/AMP/WAVE)
    - CDC module (cfg_cmd_cdc.v) for safe 25MHz->250MHz cross-domain writes
    - wr_ready handshake prevents lost commands
    - Page wrap: FREQ(0)->WAVE(1)->AMP(2)->FREQ(0)
    - Frequency step: 1Hz/10Hz/100Hz/1kHz/10kHz/100kHz/1MHz/10MHz
    - Auto-apply after each parameter change
    - Next-value computation fixes non-blocking old-value bug
    Display:
    - Live frequency display with tenth-MHz precision
    - Cursor arrow shows active parameter page
    - Waveform names, amplitude percentage, sweep/JESD/Output status
    - 500ms refresh with clean FSM (clear->write->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
    [awg_k325t.xdc, ec11_awg_bridge.v, st7789_driver.v]
